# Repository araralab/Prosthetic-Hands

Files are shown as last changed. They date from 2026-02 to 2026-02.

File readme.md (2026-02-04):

*Title:*

**Open-Source Prosthetic Hands for Community Use and STEM Education**

*Authors:*

[Rudy De-Xin de Lange](https://orcid.org/0009-0008-2099-0941), Andrew Japes, [Lucas Ferrari Gerez](https://orcid.org/0000-0002-2997-4672)

*Abstract:*

Prosthetic technologies restore function and independence of millions of individuals worldwide with limb loss and, at the same time, exemplify the complex challenges inherent to human-centred engineering and design. Meanwhile, in the United Kingdom (UK), only a small portion of secondary education students choose to pursue a career in Science, Technology, Engineering and Mathematics (STEM) fields. This creates a large discrepancy between the supply and demand of individuals to fulfil engineering and technology positions. To tackle both challenges, we propose the Ararauna, Macao and Severus open-source, affordable prosthetic hands that range from basic to advanced designs. They are intended 1) for individuals with upper limb differences and 2) as tools to assist in teaching and promoting STEM-related skills in UK secondary education.  We conducted three experiments looking into grasping capabilities, grip strength, and durability. Our results demonstrate that all three hands are suitable for use as an assistive wearable device or as an educational tool. Our work aims to encourage the prosthetic community to provide the general public with more affordable open-source medical devices intended for individual and educational use. Future work focuses on integrating the presented hands within UK secondary school curricula.

*Repository Contents:*

* .STL (individual parts)  & .STEP (assembly) files for the Ararauna, Macao, and Severus prosthetic hands.
* Some (example) code for programming each hand respectively.
* A Bill of Materials (BOM) for each hand.

*The Prosthetic Hands:*

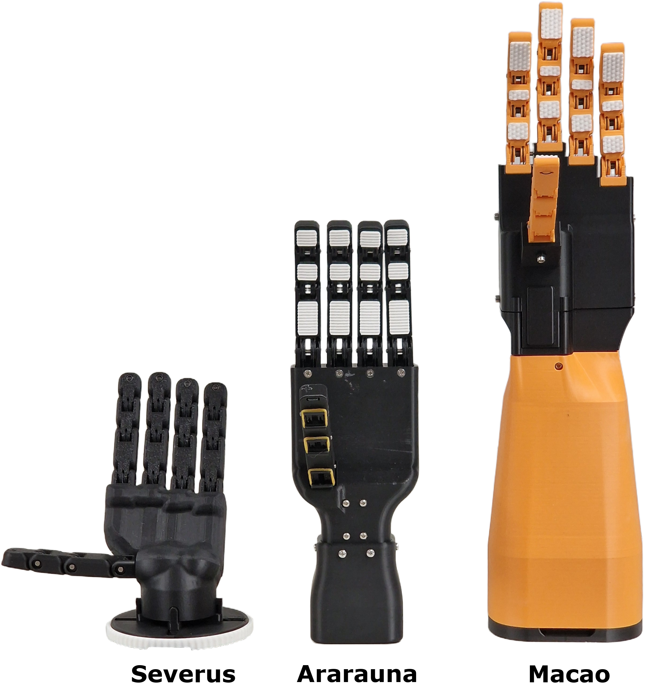
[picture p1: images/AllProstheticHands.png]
All Prosthetic Hands


*Video:*

In the [following video](https://youtu.be/XQv565ON-JM) the capabilities of the three proposed prosthetic hands (Ararauna, Macao, Severus) and two of the three different conducted experiments (Real-world Object Grasping and Grasp Durability) are shown, in that order respectively.

<p align="center">
  <a href="https://youtu.be/XQv565ON-JM">
    Video Title
  </a>
</p>

*Contact:*

For more information, please visit [our website](https://www.araralab.uk/home). Alternatively, please contact the [main author](mailto:3063568D@student.gla.ac.uk) or the [academic supervisor](mailto:Lucas.FerrariGerez@glasgow.ac.uk).

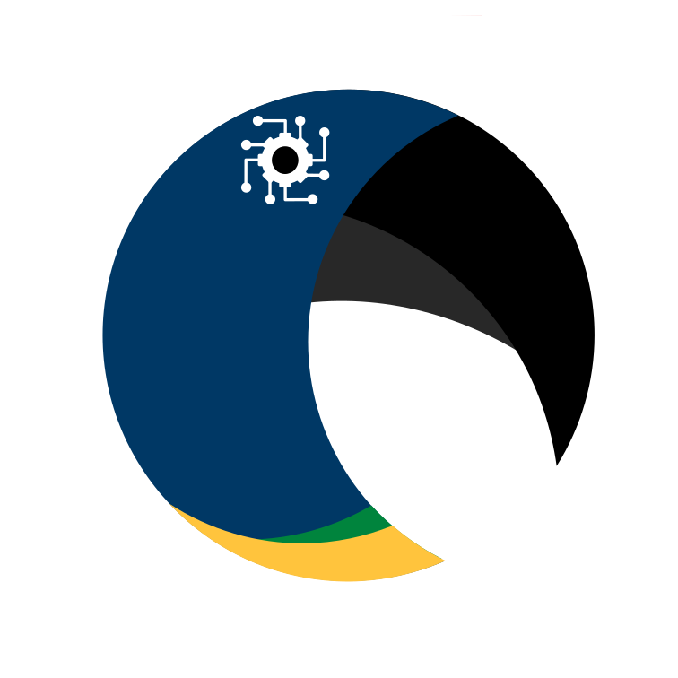
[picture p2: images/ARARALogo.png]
ARARA
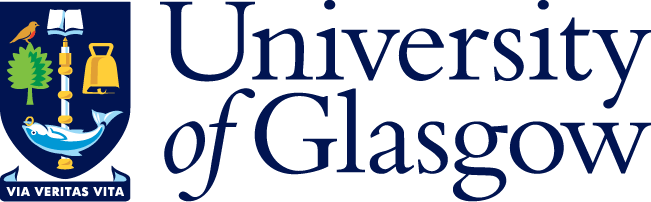
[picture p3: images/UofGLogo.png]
UofG


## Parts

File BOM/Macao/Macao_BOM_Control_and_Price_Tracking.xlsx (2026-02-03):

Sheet: Parts
BoM Control and Price Tracking
Part | Unit Price | Supplier | Notes | Quantity Per Prosthesis | Price Per Prosthesis | Quantity Ordered | Quantity Received | Quantity Used | Link
PLA Filament |  |  |  |  | £0.00
Fishing Line | £8.95 |  | 50lb x 100ft |  | £0.00 | 1.00 | 1.00 |  | https://www.amazon.co.uk/emma-kites-62Meters-Activities-Tactical/dp/B08PBXD5CH?sp_csd=d2lkZ2V0TmFtZT1zcF9hdGY
Orthodontic Bands | £0.01 |  | 4.5oz x 1/8" (£1.19 for 100) |  | £0.00 | 100.00 | 100.00 | 6.00 | https://www.ebay.co.uk/itm/276185566951
M3 Bolt pack | £11.99 |  | (1600 pcs) |  | £0.00 | 1.00 | 1.00 |  | https://www.amazon.co.uk/dp/B0DZXLY1ZX?ref=ppx_yo2ov_dt_b_fed_asin_title&th=1
 |  |  |  |  | £0.00
 |  |  |  |  | £0.00
 |  |  |  |  | £0.00
 |  |  |  |  | £0.00
 |  |  |  |  | £0.00
 |  |  |  |  | £0.00
 |  |  |  |  | £0.00
 |  |  |  |  | £0.00
 |  |  |  |  | £0.00
 |  |  |  |  | £0.00
 |  |  |  |  | £0.00
 |  |  |  |  | £0.00
 |  |  |  |  | £0.00
 |  |  |  |  | £0.00
 |  |  |  |  | £0.00
 |  |  |  |  | £0.00
 |  |  |  |  | £0.00
 |  |  |  |  | £0.00
 |  |  |  |  | £0.00
 |  |  |  |  | £0.00
 |  |  |  |  | £0.00
 |  |  |  |  | £0.00
 |  |  |  |  | £0.00
Prosthesis Parts Value |  |  |  | £0.00
Total Project Value |  |  |  | £22.13

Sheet: Tooling
Tooling Control and Price Tracking
Tool | Unit Price | Supplier | Notes | Link

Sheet: Report BoM
BOM Control and Price Tracking - Macao
Part | Unit Price | Supplier | Notes | Quantity Per Prosthesis | Price Per Prosthesis | Quantity Ordered | Quantity Received | Quantity Used | Stock | Link
PLA Filament | £17.99 | Bambu | PLA Black | 0.70 | £12.59 | 10.00 | 10.00 | 0.70 | 9.30 | https://uk.store.bambulab.com/products/pla-basic-filament
Kevlar Cord | £8.95 | Amazon | 50lb x 100ft | 1.00 | £8.95 | 1.00 | 1.00 | 0.01 | 0.99 | https://www.amazon.co.uk/emma-kites-62Meters-Activities-Tactical/dp/B08PBXD5CH?sp_csd=d2lkZ2V0TmFtZT1zcF9hdGY
Arduino R4 Wifi | £25.00 | the PiHut |  | 1.00 | £25.00 | 10.00 | 10.00 | 1.00 | 9.00 | https://thepihut.com/products/arduino-uno-r4-wifi
DFRobot Quad Motor Shield (DRI0039) | £13.27 | Digikey |  | 1.00 | £13.27 | 8.00 | 8.00 | 1.00 | 7.00 | https://www.digikey.co.uk/en/products/detail/dfrobot/DRI0039/6588612
Dupont Wires Male to Male | £5.63 | Amazon | ~20 per hand | 0.17 | £0.94 | 1.00 | 1.00 | 0.33 | 0.67 | https://www.amazon.co.uk/Elegoo-120pcs-Multicolored-Breadboard-arduino-colorful/dp/B01EV70C78
Actuonix PQ12-P | £60.00 | Robotshop |  | 4.00 | £240.00 | 32.00 | 32.00 | 4.00 | 28.00 | https://uk.robotshop.com/products/actuonix-pq12-p-linear-actuator-20mm-1001-6v-potentiometer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
11.1V Lithium Li-Ion 2600mAH Battery | £10.90 | Amazon |  | 1.00 | £10.90 | 8.00 | 8.00 | 1.00 | 7.00 | https://www.amazon.co.uk/Replacement-Rechargeable-Airplane-Doorbell-Handheld-No-Charger-Cable/dp/B0DCW2WFCP
M3 Threaded heat insert | £0.16 | Accu |  | 16.00 | £2.56 | 500.00 | 500.00 | 1.00 | 499.00 | https://www.accu.co.uk/brass-threaded-inserts/845137-HTBI-M3-BR
M3x8mm Full Thread Socket | £0.08 | Accu |  | 18.00 | £1.44 | 500.00 | 500.00 | 1.00 | 499.00 | https://www.accu.co.uk/metric-cap-head-screws/3974-SSCF-M3-8-A4
M3x12mm Full Thread Socket | £0.07 | Accu |  | 5.00 | £0.35 | 500.00 | 500.00 | 1.00 | 499.00 | https://www.accu.co.uk/metric-cap-head-screws/3976-SSCF-M3-12-A4
M3x12mm Dowel Pin | £0.13 | Accu |  | 15.00 | £1.95 | 400.00 | 400.00 | 1.00 | 399.00 | https://www.accu.co.uk/dowel-pins/72639-HDP-3-12-A1
RS PRO Miniature Push Button | £4.01 | RS Online |  | 4.00 | £16.04 | 32.00 | 32.00 | 1.00 | 31.00 | https://uk.rs-online.com/web/p/push-button-switches/7346710
 |  |  |  |  | £0.00 |  |  |  | 0.00
 |  |  |  |  | £0.00 |  |  |  | 0.00
 |  |  |  |  | £0.00 |  |  |  | 0.00
 |  |  |  |  | £0.00 |  |  |  | 0.00
 |  |  |  |  | £0.00 |  |  |  | 0.00
 |  |  |  |  | £0.00 |  |  |  | 0.00
 |  |  |  |  | £0.00 |  |  |  | 0.00
 |  |  |  |  | £0.00 |  |  |  | 0.00
 |  |  |  |  | £0.00 |  |  |  | 0.00
 |  |  |  |  | £0.00 |  |  |  | 0.00
 |  |  |  |  | £0.00 |  |  |  | 0.00
 |  |  |  |  | £0.00 |  |  |  | 0.00
 |  |  |  |  | £0.00 |  |  |  | 0.00
 |  |  |  |  | £0.00 |  |  |  | 0.00
 |  |  |  |  | £0.00 |  |  |  | 0.00
Prosthesis Parts Value |  |  |  | £333.99
Total Project Value |  |  |  | £2893.16

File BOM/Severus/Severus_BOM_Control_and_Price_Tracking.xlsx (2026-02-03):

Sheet: Parts
BoM Control and Price Tracking
Part | Unit Price | Supplier | Notes | Quantity Per Prosthesis | Price Per Prosthesis | Quantity Ordered | Quantity Received | Quantity Used | Link
PLA Filament |  |  |  |  | £0.00
Fishing Line | £8.95 |  | 50lb x 100ft |  | £0.00 | 1.00 | 1.00 |  | https://www.amazon.co.uk/emma-kites-62Meters-Activities-Tactical/dp/B08PBXD5CH?sp_csd=d2lkZ2V0TmFtZT1zcF9hdGY
Orthodontic Bands | £0.01 |  | 4.5oz x 1/8" (£1.19 for 100) |  | £0.00 | 100.00 | 100.00 | 6.00 | https://www.ebay.co.uk/itm/276185566951
M3 Bolt pack | £11.99 |  | (1600 pcs) |  | £0.00 | 1.00 | 1.00 |  | https://www.amazon.co.uk/dp/B0DZXLY1ZX?ref=ppx_yo2ov_dt_b_fed_asin_title&th=1
 |  |  |  |  | £0.00
 |  |  |  |  | £0.00
 |  |  |  |  | £0.00
 |  |  |  |  | £0.00
 |  |  |  |  | £0.00
 |  |  |  |  | £0.00
 |  |  |  |  | £0.00
 |  |  |  |  | £0.00
 |  |  |  |  | £0.00
 |  |  |  |  | £0.00
 |  |  |  |  | £0.00
 |  |  |  |  | £0.00
 |  |  |  |  | £0.00
 |  |  |  |  | £0.00
 |  |  |  |  | £0.00
 |  |  |  |  | £0.00
 |  |  |  |  | £0.00
 |  |  |  |  | £0.00
 |  |  |  |  | £0.00
 |  |  |  |  | £0.00
 |  |  |  |  | £0.00
 |  |  |  |  | £0.00
 |  |  |  |  | £0.00
Prosthesis Parts Value |  |  |  | £0.00
Total Project Value |  |  |  | £22.13

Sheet: Tooling
Tooling Control and Price Tracking
Tool | Unit Price | Supplier | Notes | Link

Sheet: Report BoM
BOM Control and Price Tracking - Severus
Part | Unit Price | Supplier | Notes | Quantity Per Prosthesis | Price Per Prosthesis | Quantity Ordered | Quantity Received | Quantity Used | Stock | Link
PLA Filament | £18.99 | Creality | Hyper PLA (Black) - 1kg | 0.35 | £6.65 | 1.00 | 1.00 | 0.70 | 0.30 | Hyper 1.75mm PLA 3D Printing Filament 1kg (https://store.creality.com/uk/products/hyper-1-75mm-pla-3d-printing-filament-1kg)
Kevlar Cord | £8.95 | Amazon | 50lb x 100ft | 0.03 | £0.27 | 1.00 | 1.00 | 0.05 | 0.95 | https://www.amazon.co.uk/emma-kites-62Meters-Activities-Tactical/dp/B08PBXD5CH?sp_csd=d2lkZ2V0TmFtZT1zcF9hdGY
Orthodontic Bands | £0.01 | Ebay | 4.5oz x 1/8" (£1.19 for 100) | 15.00 | £0.18 | 100.00 | 100.00 | 6.00 | 94.00 | https://www.ebay.co.uk/itm/276185566951
M3 Bolt pack | £0.01 | Amazon | (1600 pcs) | 46.00 | £0.34 | 1600.00 | 1600.00 | 60.00 | 1540.00 | https://www.amazon.co.uk/dp/B0DZXLY1ZX?ref=ppx_yo2ov_dt_b_fed_asin_title&th=1
Barrel Nuts/Binding screws | £0.30 | Harfington | M2 x 12mm | 15.00 | £4.50 | 20.00 | 20.00 | 19.00 | 1.00 | M2/M3/M4/M5 Binding Barrels and Screws Hex Socket Drive 18-8 Stainless Steel | Harfington (https://www.harfington.com/en-gb/products/p-1528129?variant=45273319047417)
Nylon Shoulder Washers | £0.10 | Components Direct |  | 30.00 | £3.01 | 100.00 | 100.00 | 36.00 | 64.00 | Buy Nylon Shoulder Bushes | Machine Screw Insulators (https://www.components-direct.com/component-and-fastener-products/nylon-shoulder-washers-machine-screw-insulators/INS003-NAT)
Micro-metal Geared Motor (100:1) | £11.50 | The Pi Hut |  | 5.00 | £57.50 | 5.00 | 5.00 | 5.00 | 0.00 | Micro Metal Geared Motor with Encoder - 6V 155RPM 100:1 - The Pi Hut (https://thepihut.com/products/micro-metal-geared-motor-w-encoder-6v-155rpm-100-1)
Micro-metal Geared Motor (380:1) | £11.50 | The Pi Hut |  | 1.00 | £11.50 | 2.00 | 2.00 | 1.00 | 1.00 | Micro Metal Geared motor with Encoder - 6V 41RPM 380:1 - The Pi Hut (https://thepihut.com/products/micro-metal-geared-motor-w-encoder-6v-41rpm-380-1)
2N7000 MOSFET Transistor | £0.08 | Amazon |  | 6.00 | £0.48 | 100.00 | 100.00 | 8.00 | 92.00 | ACOLY 100 Pcs Direct Insertion Transistor 2N7000 TO-92 N-Channel Feld Effect Transistor 0.3A 60V : Amazon.co.uk: Business, Industry & Science (https://www.amazon.co.uk/dp/B0FVX46NM9?ref_=pe_112168041_1111392281_t_fed_asin_title)
220 Ohm Resistor | £0.01 | RS |  | 6.00 | £0.06 |  |  |  | 0.00
10K Ohm Resistor | £0.01 | RS |  | 6.00 | £0.06 |  |  |  | 0.00
100K Ohm Resistor | £0.01 | RS |  | 6.00 | £0.06 |  |  |  | 0.00
STM32F411CEU6 Blackpill Development Board | £15.90 | The Pi Hut |  | 1.00 | £15.90 | 1.00 | 1.00 | 1.00 | 0.00 | STM32F411 "BlackPill" Development Board - The Pi Hut (https://thepihut.com/products/stm32f411-blackpill-development-board)
TB6612FNG Dual Motor Driver Board | £5.80 | The Pi Hut |  | 3.00 | £17.40 | 3.00 | 3.00 | 3.00 | 0.00 | Pololu TB6612FNG Dual Motor Driver Carrier - The Pi Hut (https://thepihut.com/products/pololu-tb6612fng-dual-motor-driver-carrier)
M3 Threaded heat-press inserts | £0.08 | 3D Prima | Ruthex inserts | 5.00 | £0.38 | 100.00 | 100.00 | 12.00 | 88.00 | Ruthex M3 threaded insert – Rx-M3x5.7 - 100 pcs | 3D Prima (https://www.3dprima.co.uk/ruthex-m3-threaded-insert-rx-m3x5-7-100-pcs-12611)
 |  |  |  |  | £0.00 |  |  |  | 0.00
 |  |  |  |  | £0.00 |  |  |  | 0.00
 |  |  |  |  | £0.00 |  |  |  | 0.00
 |  |  |  |  | £0.00 |  |  |  | 0.00
 |  |  |  |  | £0.00 |  |  |  | 0.00
 |  |  |  |  | £0.00 |  |  |  | 0.00
 |  |  |  |  | £0.00 |  |  |  | 0.00
 |  |  |  |  | £0.00 |  |  |  | 0.00
 |  |  |  |  | £0.00 |  |  |  | 0.00
 |  |  |  |  | £0.00 |  |  |  | 0.00
 |  |  |  |  | £0.00 |  |  |  | 0.00
 |  |  |  |  | £0.00 |  |  |  | 0.00
Prosthesis Parts Value |  |  |  | £118.28
Total Project Value |  |  |  | £186.50

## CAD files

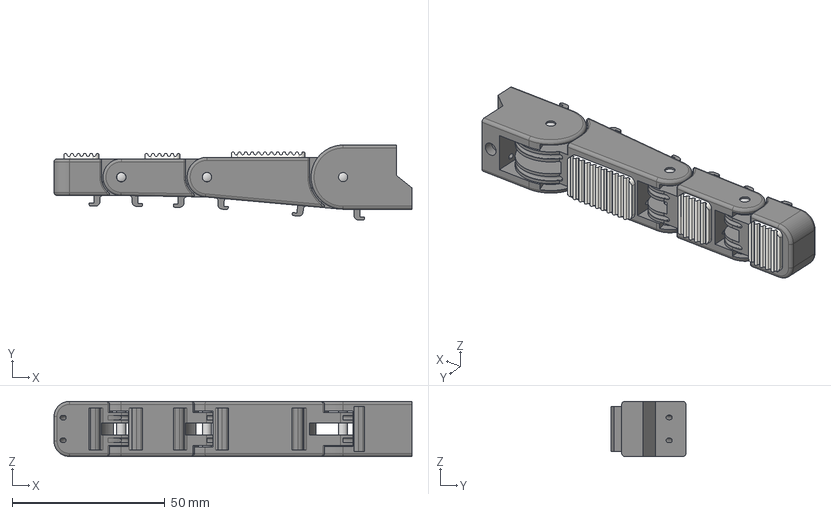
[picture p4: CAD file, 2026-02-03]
.STL&.STEP/Ararauna/Assembly/Ararauna Finger Assembly.step
117.0 x 24.5 x 18.0 mm
Basic_Finger_Distal v19
Basic_Finger_Middle v16
Basic_Finger_Proximal v13
Base
Basic_Finger_Proximal_Pad v9
Basic_Finger_Middle_Pad v11
Basic_Finger_Middle_Pad v11 (1)
91595A118_Dowel Pin
91595A118_Dowel Pin_1
91595A118_Dowel Pin_2

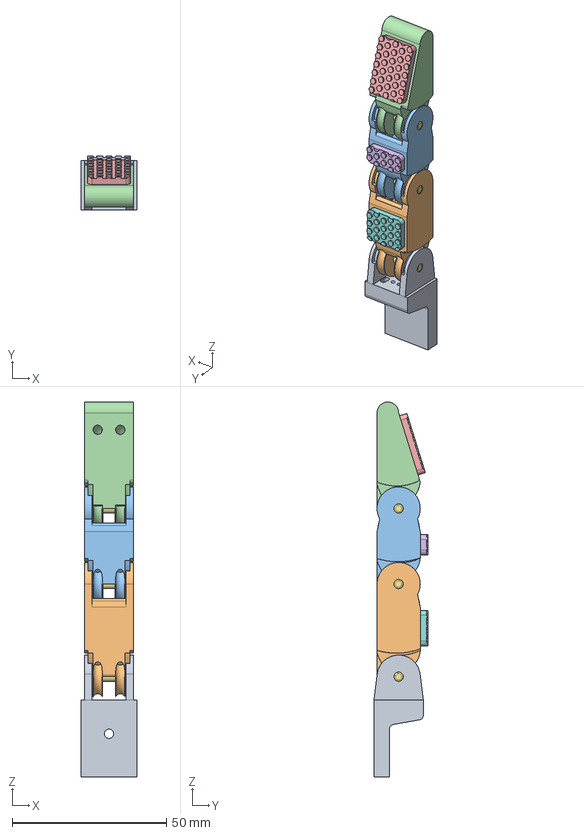
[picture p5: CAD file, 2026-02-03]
.STL&.STEP/Macao/Assembly/Macao Finger Assembly.step
18.0 x 17.5 x 121.5 mm
Finger Base
Finger First Phalange
Finger Medial Phalange
Finger Distal Phalange
Finger Distal Pad
Finger Medial Pad
Dowel Pin Distal
Dowel Pin Medial
Finger First Pad
Dowel Pin Base

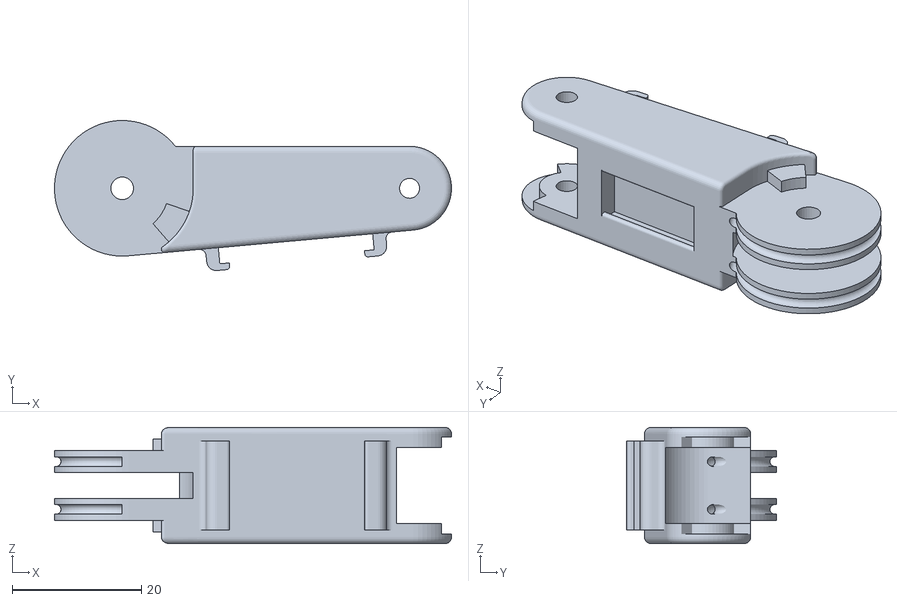
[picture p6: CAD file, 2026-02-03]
.STL&.STEP/Ararauna/Fingers/Finger Proximal Phalange.stl
61.5 x 23.2 x 18.0

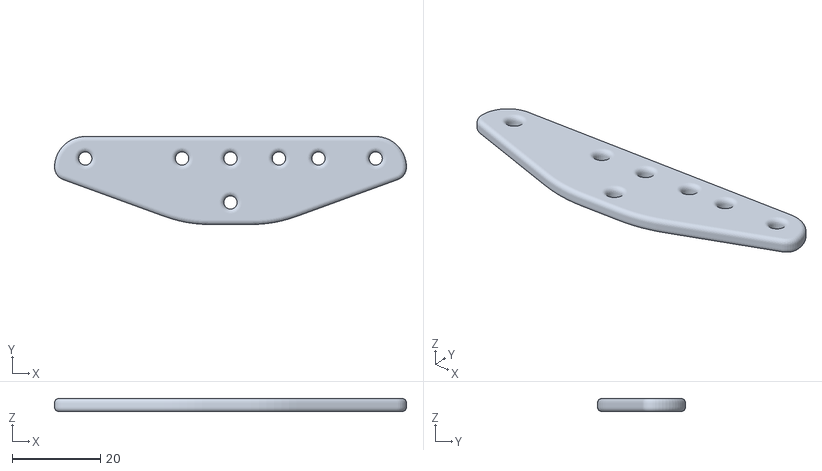
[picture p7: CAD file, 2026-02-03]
.STL&.STEP/Ararauna/Hand/Finger Differential.stl
80.0 x 20.0 x 3.00

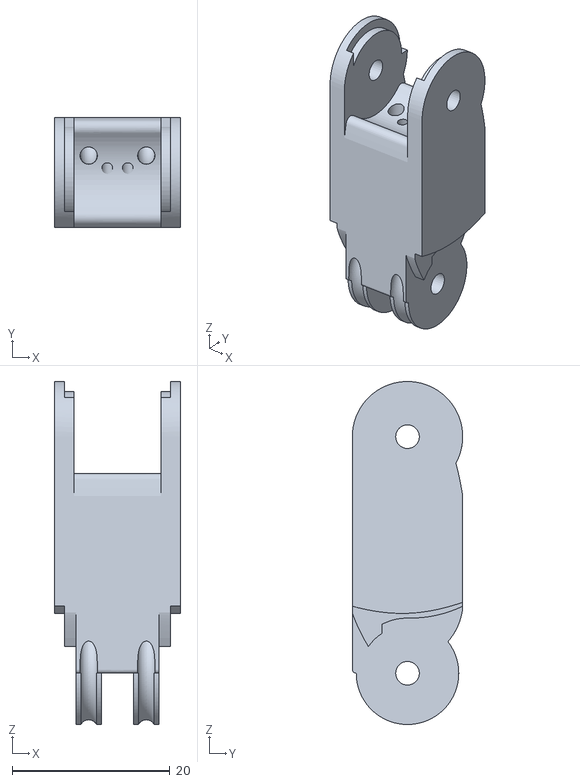
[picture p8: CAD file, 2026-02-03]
.STL&.STEP/Macao/Fingers/Finger First Phalange.stl
16.0 x 14.0 x 43.5

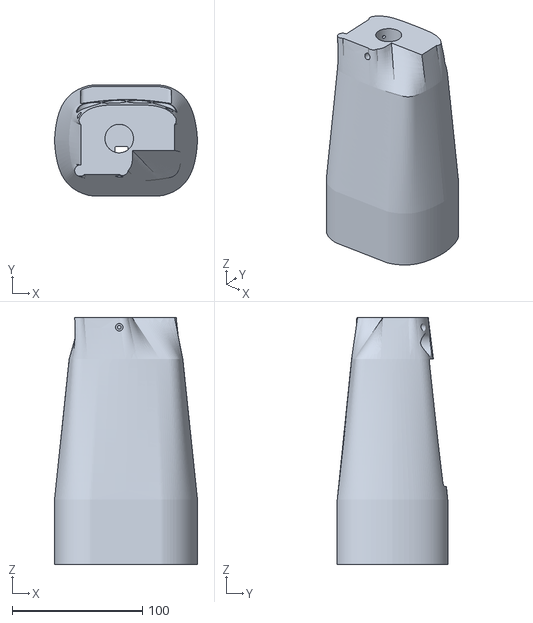
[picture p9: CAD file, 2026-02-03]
.STL&.STEP/Macao/Forearm/Short Forearm.stl
110.0 x 85.0 x 190.0

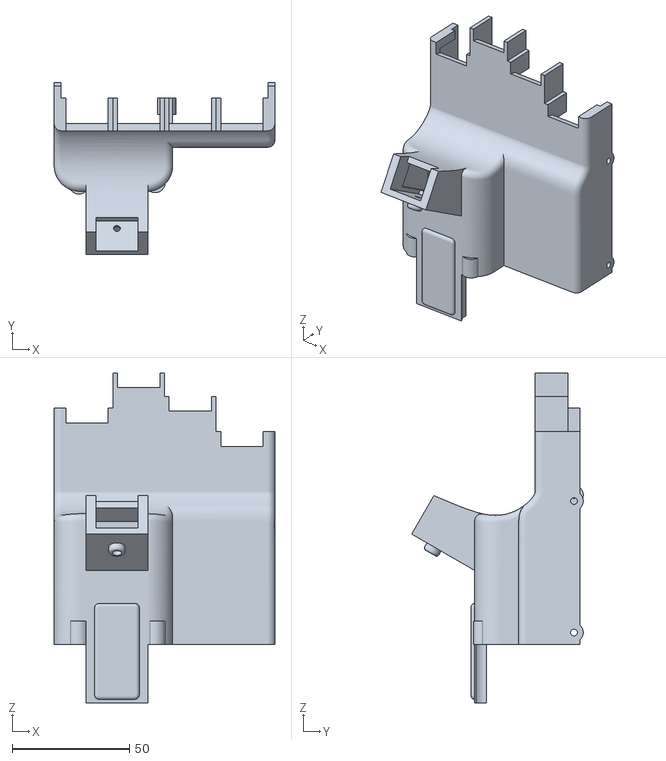
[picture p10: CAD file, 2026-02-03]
.STL&.STEP/Macao/Hand/HandPalm Outer Segment.stl
94.0 x 73.1 x 140.6

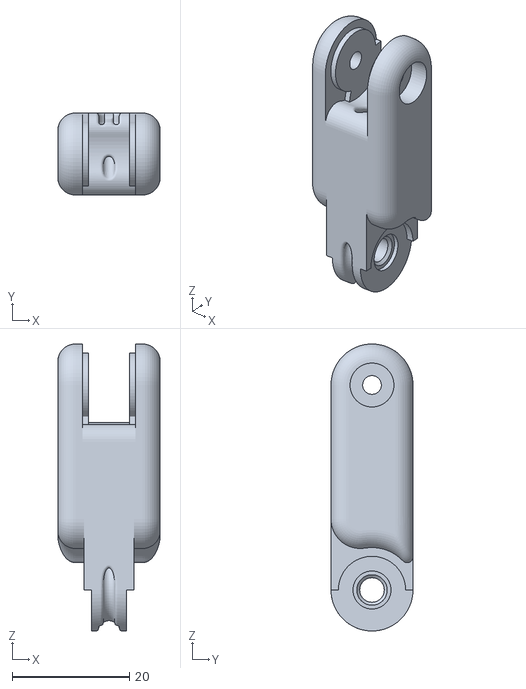
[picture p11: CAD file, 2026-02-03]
.STL&.STEP/Severus/Fingers/Proximal Phalange.stl
17.5 x 14.0 x 49.0

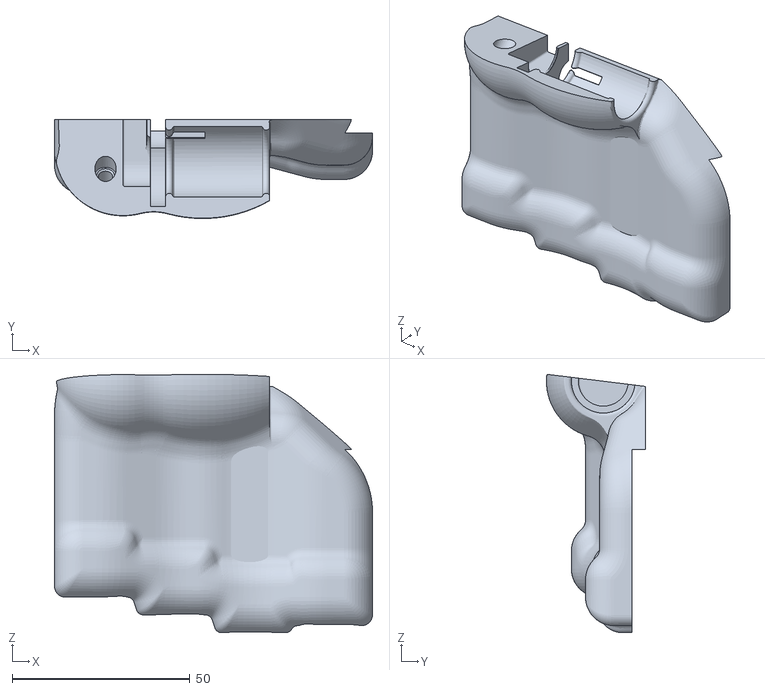
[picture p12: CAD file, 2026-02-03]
.STL&.STEP/Severus/Hand/Palm.stl
89.4 x 27.9 x 72.6

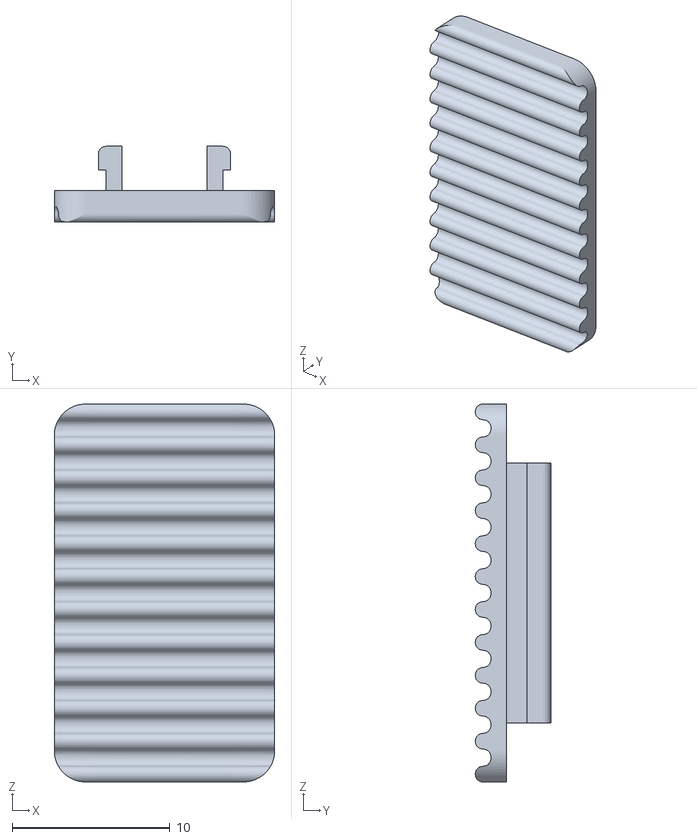
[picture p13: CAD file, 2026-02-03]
.STL&.STEP/Ararauna/Fingers/Finger Proximal Pad.stl
14.0 x 4.80 x 24.0

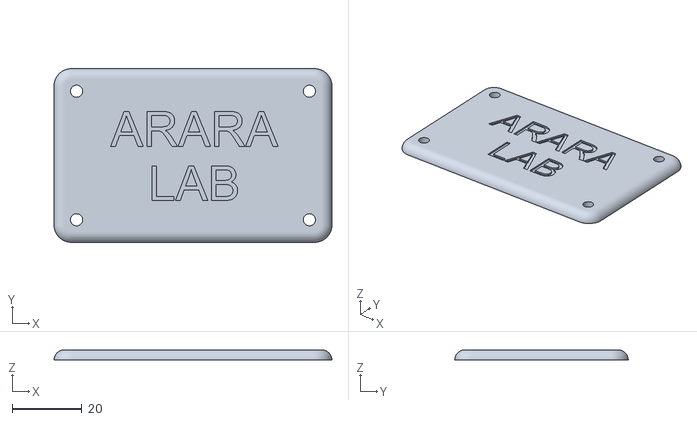
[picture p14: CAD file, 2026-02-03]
.STL&.STEP/Ararauna/Hand/Back Cover.stl
80.0 x 50.0 x 3.00

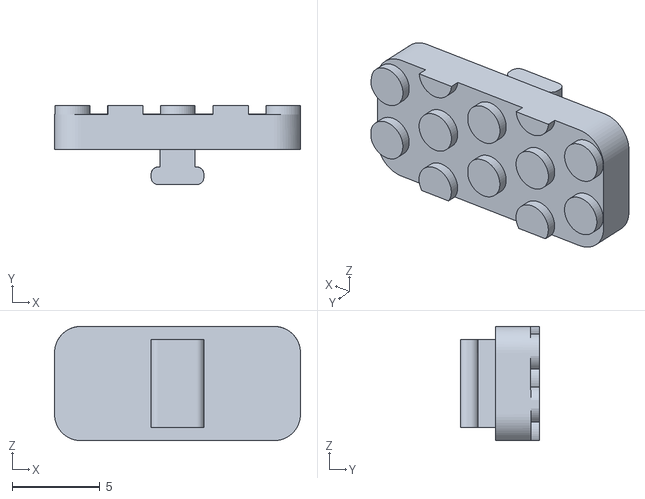
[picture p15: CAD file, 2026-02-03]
.STL&.STEP/Macao/Fingers/Finger Medial Pad.stl
14.0 x 4.51 x 6.50

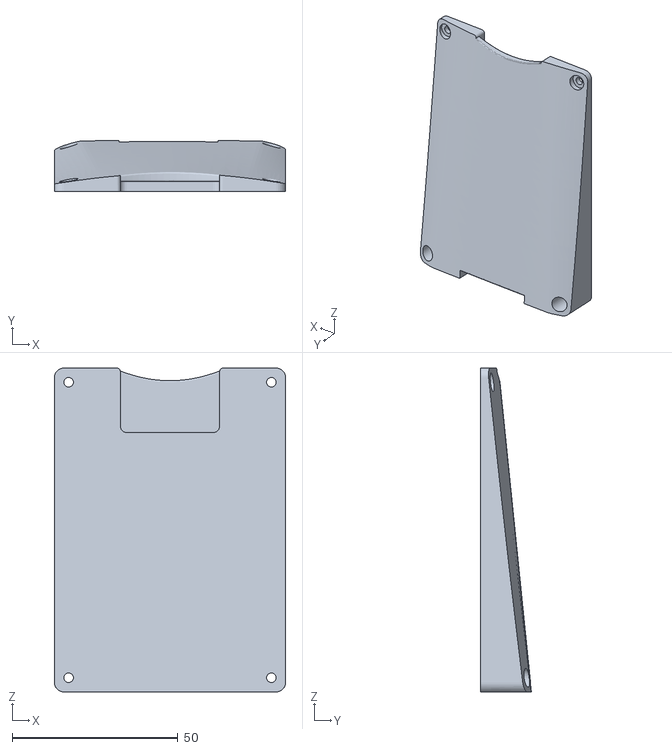
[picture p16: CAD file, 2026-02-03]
.STL&.STEP/Macao/Forearm/Short Forearm Arduino Cavity Lid.stl
69.8 x 15.3 x 97.8

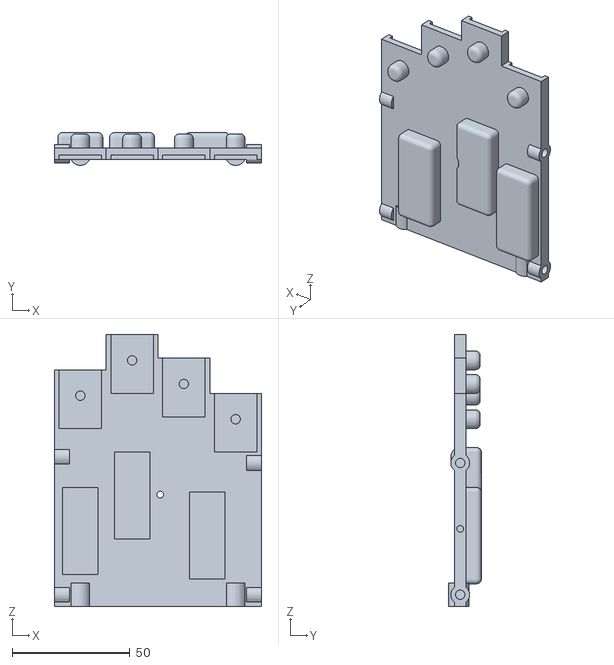
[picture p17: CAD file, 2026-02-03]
.STL&.STEP/Macao/Hand/HandPalm Middle Segment.stl
88.0 x 13.9 x 115.6

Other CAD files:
.STL&.STEP/Severus/Fingers/Thumb Motor Holder.stl
.STL&.STEP/Severus/Hand/Wrist.stl
.STL&.STEP/Ararauna/Fingers/Finger Middle Phalange.stl
.STL&.STEP/Ararauna/Hand/Hand Palm.stl
.STL&.STEP/Ararauna/Fingers/Finger Base.stl
.STL&.STEP/Ararauna/Fingers/Finger Distal Phalange.stl
.STL&.STEP/Ararauna/Fingers/Finger Middle Pad.stl
.STL&.STEP/Ararauna/Hand/Wrist.stl
.STL&.STEP/Macao/Fingers/Finger Base.stl
.STL&.STEP/Macao/Fingers/Finger Distal Pad.stl
.STL&.STEP/Macao/Fingers/Finger Distal Phalange.stl
.STL&.STEP/Macao/Fingers/Finger First Pad.stl
.STL&.STEP/Macao/Fingers/Finger Medial Phalange.stl
.STL&.STEP/Macao/Forearm/Short Forearm Base Lid.stl
.STL&.STEP/Macao/Hand/Palm Cover.stl
.STL&.STEP/Severus/Fingers/Distal Phalange.stl
.STL&.STEP/Severus/Fingers/Finger Motor Holder.stl
.STL&.STEP/Severus/Fingers/Fingernail Phalange.stl
.STL&.STEP/Severus/Fingers/Middle Phalange.stl
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

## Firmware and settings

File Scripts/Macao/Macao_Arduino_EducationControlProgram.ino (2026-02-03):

//////////////////////////////////////////////////////////////////////////////
// Button & Keyboard-Controlled Multi-Grasp System for ARARA UNO Prosthetic //
//////////////////////////////////////////////////////////////////////////////
// Button 1 (Pin 2):  Open Hand
// Button 2 (Pin 9):  Power Grasp (all fingers closed)
// Button 3 (Pin 10): Fine Pinch (thumb + middle closed)
// Button 4 (Pin 13): Tripod (thumb + middle + index closed)
//
// Keyboard Controls (via Serial):
// Key 0: Open Hand (all fingers extended)
// Key 1: Power Grasp (all fingers closed)
// Key 2: Fine Pinch (thumb + middle closed, index + ring+pinky extended)
// Key 3: Tripod (thumb + middle + index closed, ring+pinky extended)
// Key 4: Point (thumb + middle + ring+pinky closed, index extended)
// Key 5: Peace Sign (thumb + ring+pinky closed, index + middle extended)
// Key 6: Close Thumb only
// Key 7: Close Index only
// Key 8: Close Middle only
// Key 9: Close Ring+Pinky only
//////////////////////////////////////////////////////////////////////////////
// Written & Maintained by: Rudy de Lange (3063568D@student.gla.ac.uk)
// Last maintained: 13/01/2026 - Added button control + Fixed Logic
//////////////////////////////////////////////////////////////////////////////

// Motor pins
#define M1_DIR 7     // Middle finger (physically wired)
#define E1_PWM 6
#define M2_DIR 4     // Index Finger
#define E2_PWM 3
#define M3_DIR 8     // Thumb
#define E3_PWM 5
#define M4_DIR 12    // Ring + Pinky (physically wired)
#define E4_PWM 11

// Button pins
#define BUTTON_1 1   // Open Hand
#define BUTTON_2 9   // Power Grasp
#define BUTTON_3 13  // Fine Pinch
#define BUTTON_4 10  // Tripod

// Timing constants
#define FINGER_EXTEND_TIME 3000
#define FINGER_RETRACT_TIME 3000
#define THUMB_RETRACT_TIME 3000    
#define THUMB_DELAY 480            // Delay before thumb starts closing
#define THUMB_PINCH_DELAY 200      // Delay before thumb starts closing for fine pinch
#define DEBOUNCE_DELAY 50          // Button debounce delay in ms

// Motor speeds
#define MOTOR_SPEED 255

// State tracking
enum GraspType {
  OPEN,
  POWER_GRASP,
  FINE_PINCH,
  TRIPOD,
  POINT,
  PEACE_SIGN,
  THUMB_ONLY,
  INDEX_ONLY,
  MIDDLE_ONLY,
  RING_PINKY_ONLY
};

GraspType currentGrasp = OPEN;

// Button state tracking
int lastBtn1 = HIGH;
int lastBtn2 = HIGH;
int lastBtn3 = HIGH;
int lastBtn4 = HIGH;

void setup() {
  Serial.begin(9600);
  Serial.println(F("=== Multi-Grasp Control System ==="));
  Serial.println(F("--- Button Controls ---"));
  Serial.println(F("Button 1 (Pin 2):  Open Hand"));
  Serial.println(F("Button 2 (Pin 9):  Power Grasp"));
  Serial.println(F("Button 3 (Pin 10): Fine Pinch"));
  Serial.println(F("Button 4 (Pin 13): Tripod"));
  Serial.println(F("--- Keyboard Controls ---"));
  Serial.println(F("0: Open Hand"));
  Serial.println(F("1: Power Grasp"));
  Serial.println(F("2: Fine Pinch"));
  Serial.println(F("3: Tripod"));
  Serial.println(F("4: Point"));
  Serial.println(F("5: Peace Sign"));
  Serial.println(F("6: Close Thumb only"));
  Serial.println(F("7: Close Index only"));
  Serial.println(F("8: Close Middle only"));
  Serial.println(F("9: Close Ring+Pinky only"));

  // Initialize motor pins
  pinMode(M1_DIR, OUTPUT);
  pinMode(E1_PWM, OUTPUT);
  pinMode(M2_DIR, OUTPUT);
  pinMode(E2_PWM, OUTPUT);
  pinMode(M3_DIR, OUTPUT);
  pinMode(E3_PWM, OUTPUT);
  pinMode(M4_DIR, OUTPUT);
  pinMode(E4_PWM, OUTPUT);

  // Initialize button pins with internal pull-up resistors
  pinMode(BUTTON_1, INPUT_PULLUP);
  pinMode(BUTTON_2, INPUT_PULLUP);
  pinMode(BUTTON_3, INPUT_PULLUP);
  pinMode(BUTTON_4, INPUT_PULLUP);

  // Stop all motors
  digitalWrite(M1_DIR, LOW);
  digitalWrite(M2_DIR, LOW);
  digitalWrite(M3_DIR, LOW);
  digitalWrite(M4_DIR, LOW);
  analogWrite(E1_PWM, 0);
  analogWrite(E2_PWM, 0);
  analogWrite(E3_PWM, 0);
  analogWrite(E4_PWM, 0);

  delay(1000);

  // Initialize to open position
  Serial.println(F("Initializing to open position..."));
  openAllFingers();

  Serial.println(F("Ready!"));
}

void loop() {
  // Check button inputs
  checkButtons();

  // Check serial keyboard inputs
  if (Serial.available() > 0) {
    char key = Serial.read();
    handleKeyboardInput(key);
  }

  delay(10);
}

// ========== BUTTON HANDLING ==========

void checkButtons() {
  // Read button states
  int btn1 = digitalRead(BUTTON_1);
  int btn2 = digitalRead(BUTTON_2);
  int btn3 = digitalRead(BUTTON_3);
  int btn4 = digitalRead(BUTTON_4);

  // Button 1 - Open Hand (trigger on press: LOW->HIGH transition)
  if (btn1 != lastBtn1) {
    if (btn1 == HIGH) {  // Button pressed (HIGH = pressed)
      Serial.println(F("Button 1 pressed: Open Hand"));
      openAllFingers();
      currentGrasp = OPEN;
      Serial.println(F(">>> OPEN"));
    }
    lastBtn1 = btn1;
    delay(50);  // Debounce
  }

  // Button 2 - Power Grasp
  if (btn2 != lastBtn2) {
    if (btn2 == HIGH) {  // Button pressed
      Serial.println(F("Button 2 pressed: Power Grasp"));
      if (currentGrasp == POWER_GRASP) {
        openAllFingers();
        currentGrasp = OPEN;
        Serial.println(F(">>> OPEN"));
      } else if (currentGrasp == OPEN) {
        performPowerGrasp();
        currentGrasp = POWER_GRASP;
        Serial.println(F(">>> POWER GRASP"));
      } else {
        Serial.println(F("ERROR: Release hand first (press Button 1)"));
      }
    }
    lastBtn2 = btn2;
    delay(50);
  }

  // Button 3 - Fine Pinch
  if (btn3 != lastBtn3) {
    if (btn3 == HIGH) {  // Button pressed
      Serial.println(F("Button 3 pressed: Fine Pinch"));
      if (currentGrasp == FINE_PINCH) {
        openAllFingers();
        currentGrasp = OPEN;
        Serial.println(F(">>> OPEN"));
      } else if (currentGrasp == OPEN) {
        performFinePinch();
        currentGrasp = FINE_PINCH;
        Serial.println(F(">>> FINE PINCH"));
      } else {
        Serial.println(F("ERROR: Release hand first (press Button 1)"));
      }
    }
    lastBtn3 = btn3;
    delay(50);
  }

  // Button 4 - Tripod
  if (btn4 != lastBtn4) {
    if (btn4 == HIGH) {  // Button pressed
      Serial.println(F("Button 4 pressed: Tripod"));
      if (currentGrasp == TRIPOD) {
        openAllFingers();
        currentGrasp = OPEN;
        Serial.println(F(">>> OPEN"));
      } else if (currentGrasp == OPEN) {
        performTripod();
        currentGrasp = TRIPOD;
        Serial.println(F(">>> TRIPOD"));
      } else {
        Serial.println(F("ERROR: Release hand first (press Button 1)"));
      }
    }
    lastBtn4 = btn4;
    delay(50);
  }
}

// ========== KEYBOARD HANDLING ==========

void handleKeyboardInput(char key) {
  switch (key) {
    case '0':
      openAllFingers();
      currentGrasp = OPEN;
      Serial.println(F(">>> OPEN"));
      break;

    case '1':
      if (currentGrasp == POWER_GRASP) {
        openAllFingers();
        currentGrasp = OPEN;
        Serial.println(F(">>> OPEN"));
      } else if (currentGrasp == OPEN) {
        performPowerGrasp();
        currentGrasp = POWER_GRASP;
        Serial.println(F(">>> POWER GRASP"));
      } else {
        Serial.println(F("ERROR: Release hand first (press 0 or Button 1)"));
      }
      break;

    case '2':
      if (currentGrasp == FINE_PINCH) {
        openAllFingers();
        currentGrasp = OPEN;
        Serial.println(F(">>> OPEN"));
      } else if (currentGrasp == OPEN) {
        performFinePinch();
        currentGrasp = FINE_PINCH;
        Serial.println(F(">>> FINE PINCH"));
      } else {
        Serial.println(F("ERROR: Release hand first (press 0 or Button 1)"));
      }
      break;

    case '3':
      if (currentGrasp == TRIPOD) {
        openAllFingers();
        currentGrasp = OPEN;
        Serial.println(F(">>> OPEN"));
      } else if (currentGrasp == OPEN) {
        performTripod();
        currentGrasp = TRIPOD;
        Serial.println(F(">>> TRIPOD"));
      } else {
        Serial.println(F("ERROR: Release hand first (press 0 or Button 1)"));
      }
      break;

    case '4':
      if (currentGrasp == POINT) {
        openAllFingers();
        currentGrasp = OPEN;
        Serial.println(F(">>> OPEN"));
      } else if (currentGrasp == OPEN) {
        performPoint();
        currentGrasp = POINT;
        Serial.println(F(">>> POINT"));
      } else {
        Serial.println(F("ERROR: Release hand first (press 0 or Button 1)"));
      }
      break;

    case '5':
      if (currentGrasp == PEACE_SIGN) {
        openAllFingers();
        currentGrasp = OPEN;
        Serial.println(F(">>> PEACE SIGN"));
      } else if (currentGrasp == OPEN) {
        performPeaceSign();
        currentGrasp = PEACE_SIGN;
        Serial.println(F(">>> PEACE SIGN"));
      } else {
        Serial.println(F("ERROR: Release hand first (press 0 or Button 1)"));
      }
      break;

    case '6':
      if (currentGrasp == THUMB_ONLY) {
        openAllFingers();
        currentGrasp = OPEN;
        Serial.println(F(">>> THUMB ONLY"));
      } else if (currentGrasp == OPEN) {
        performThumbOnly();
        currentGrasp = THUMB_ONLY;
        Serial.println(F(">>> THUMB ONLY"));
      } else {
        Serial.println(F("ERROR: Release hand first (press 0 or Button 1)"));
      }
      break;

    case '7':
      if (currentGrasp == INDEX_ONLY) {
        openAllFingers();
        currentGrasp = OPEN;
        Serial.println(F(">>> INDEX ONLY"));
      } else if (currentGrasp == OPEN) {
        performIndexOnly();
        currentGrasp = INDEX_ONLY;
        Serial.println(F(">>> INDEX ONLY"));
      } else {
        Serial.println(F("ERROR: Release hand first (press 0 or Button 1)"));
      }
      break;

    case '8':
      if (currentGrasp == MIDDLE_ONLY) {
        openAllFingers();
        currentGrasp = OPEN;
        Serial.println(F(">>> MIDDLE ONLY"));
      } else if (currentGrasp == OPEN) {
        performMiddleOnly();
        currentGrasp = MIDDLE_ONLY;
        Serial.println(F(">>> MIDDLE ONLY"));
      } else {
        Serial.println(F("ERROR: Release hand first (press 0 or Button 1)"));
      }
      break;

    case '9':
      if (currentGrasp == RING_PINKY_ONLY) {
        openAllFingers();
        currentGrasp = OPEN;
        Serial.println(F(">>> RING+PINKY ONLY"));
      } else if (currentGrasp == OPEN) {
        performRingPinkyOnly();
        currentGrasp = RING_PINKY_ONLY;
        Serial.println(F(">>> RING+PINKY ONLY"));
      } else {
        Serial.println(F("ERROR: Release hand first (press 0 or Button 1)"));
      }
      break;
  }
}

// ========== HELPER FUNCTIONS ==========

void openAllFingers() {
  Serial.println(F("Opening all fingers..."));

  // Set all to extend
  digitalWrite(M1_DIR, LOW);    // Middle extend 
  digitalWrite(M2_DIR, HIGH);   // Index extend
  digitalWrite(M3_DIR, HIGH);   // Thumb extend
  digitalWrite(M4_DIR, LOW);    // Ring+Pinky extend 

  // Start all motors
  analogWrite(E1_PWM, MOTOR_SPEED);
  analogWrite(E2_PWM, MOTOR_SPEED);
  analogWrite(E3_PWM, MOTOR_SPEED);
  analogWrite(E4_PWM, MOTOR_SPEED);

  delay(FINGER_EXTEND_TIME);

  // Stop all motors
  analogWrite(E1_PWM, 0);
  analogWrite(E2_PWM, 0);
  analogWrite(E3_PWM, 0);
  analogWrite(E4_PWM, 0);
}

void stopAllMotors() {
  analogWrite(E1_PWM, 0);
  analogWrite(E2_PWM, 0);
  analogWrite(E3_PWM, 0);
  analogWrite(E4_PWM, 0);
}

// ========== GRASP FUNCTIONS ==========

void performPowerGrasp() {
  // Close: Index, Ring+Pinky, Middle, Thumb (delayed)
  Serial.println(F("Power Grasp..."));

  // Set directions
  digitalWrite(M1_DIR, HIGH);   // Middle retract 
  digitalWrite(M2_DIR, LOW);    // Index retract
  digitalWrite(M3_DIR, LOW);    // Thumb retract
  digitalWrite(M4_DIR, HIGH);   // Ring+Pinky retract 

  // Start fingers first (not thumb)
  analogWrite(E2_PWM, MOTOR_SPEED);  // Index
  analogWrite(E1_PWM, MOTOR_SPEED);  // Middle 
  analogWrite(E4_PWM, MOTOR_SPEED);  // Ring+Pinky 

  delay(THUMB_DELAY);
  // Start thumb
  analogWrite(E3_PWM, MOTOR_SPEED);
  delay(THUMB_RETRACT_TIME);
  // Stop thumb at 50%
  analogWrite(E3_PWM, 0);

  // Wait for other fingers to finish
  delay(FINGER_RETRACT_TIME - THUMB_RETRACT_TIME - THUMB_DELAY);

  stopAllMotors();
}

void performFinePinch() {
  Serial.println(F("Fine Pinch..."));

  // Retract index and thumb only
  digitalWrite(M2_DIR, LOW);    // Index retract
  digitalWrite(M3_DIR, LOW);    // Thumb retract

  analogWrite(E2_PWM, MOTOR_SPEED);  // Index

  delay(THUMB_PINCH_DELAY);
  // Start thumb
  analogWrite(E3_PWM, MOTOR_SPEED);
  delay(THUMB_RETRACT_TIME);
  // Stop thumb at 50%
  analogWrite(E3_PWM, 0);

  // Wait for Index to finish
  delay(FINGER_RETRACT_TIME - THUMB_RETRACT_TIME);

  stopAllMotors();
}

void performTripod() {
  Serial.println(F("Tripod..."));

  // Retract index, middle, and thumb (keep ring+pinky extended)
  digitalWrite(M2_DIR, LOW);    // Index retract
  digitalWrite(M3_DIR, LOW);    // Thumb retract
  digitalWrite(M1_DIR, HIGH);   // Middle retract

  analogWrite(E2_PWM, MOTOR_SPEED);  // Index
  analogWrite(E1_PWM, MOTOR_SPEED);  // Middle

  delay(THUMB_DELAY);
  // Start thumb
  analogWrite(E3_PWM, MOTOR_SPEED);
  delay(THUMB_RETRACT_TIME);
  // Stop thumb at 50%
  analogWrite(E3_PWM, 0);

  // Wait for other fingers to finish
  delay(FINGER_RETRACT_TIME - THUMB_RETRACT_TIME - THUMB_DELAY);

  stopAllMotors();
}

void performPoint() {
  Serial.println(F("Point..."));

  // Retract middle, ring+pinky, and thumb (keep index extended)
  digitalWrite(M1_DIR, HIGH);   // Middle retract
  digitalWrite(M3_DIR, LOW);    // Thumb retract
  digitalWrite(M4_DIR, HIGH);   // Ring+Pinky retract

  analogWrite(E1_PWM, MOTOR_SPEED);  // Middle
  analogWrite(E4_PWM, MOTOR_SPEED);  // Ring+Pinky

  delay(THUMB_DELAY);
  // Start thumb
  analogWrite(E3_PWM, MOTOR_SPEED);
  delay(THUMB_RETRACT_TIME);
  // Stop thumb at 50%
  analogWrite(E3_PWM, 0);

  // Wait for other fingers to finish
  delay(FINGER_RETRACT_TIME - THUMB_RETRACT_TIME - THUMB_DELAY);

  stopAllMotors();
}

void performPeaceSign() {
  Serial.println(F("Peace Sign..."));

  // Retract middle, ring+pinky, and thumb (keep index+middle extended)
  digitalWrite(M1_DIR, HIGH);   // Middle retract
  digitalWrite(M3_DIR, LOW);    // Thumb retract
  digitalWrite(M4_DIR, HIGH);   // Ring+Pinky retract

  analogWrite(E1_PWM, MOTOR_SPEED);  // Middle
  analogWrite(E4_PWM, MOTOR_SPEED);  // Ring+Pinky

  delay(THUMB_DELAY);
  // Start thumb
  analogWrite(E3_PWM, MOTOR_SPEED);
  delay(THUMB_RETRACT_TIME);
  // Stop thumb at 50%
  analogWrite(E3_PWM, 0);

  // Wait for other fingers to finish
  delay(FINGER_RETRACT_TIME - THUMB_RETRACT_TIME - THUMB_DELAY);

  stopAllMotors();
}

void performThumbOnly() {
  Serial.println(F("Thumb Only..."));

  // Retract thumb only
  digitalWrite(M3_DIR, LOW);    // Thumb retract
  analogWrite(E3_PWM, MOTOR_SPEED);

  delay(THUMB_RETRACT_TIME);
  // Stop thumb at 50%
  analogWrite(E3_PWM, 0);

  stopAllMotors();
}

void performIndexOnly() {
  Serial.println(F("Index Only..."));
  // Retract index only
  digitalWrite(M2_DIR, LOW);    // Index retract
  analogWrite(E2_PWM, MOTOR_SPEED);   // Index Finger

  delay(FINGER_RETRACT_TIME);
  stopAllMotors();
}

void performMiddleOnly() {
  Serial.println(F("Middle Only..."));
  // Retract middle only
  digitalWrite(M1_DIR, HIGH);   // Middle retract
  analogWrite(E1_PWM, MOTOR_SPEED);  // Middle Finger

  delay(FINGER_RETRACT_TIME);
  stopAllMotors();
}

void performRingPinkyOnly() {
  Serial.println(F("Ring+Pinky Only..."));
  // Retract ring+pinky only
  digitalWrite(M4_DIR, HIGH);   // Ring+Pinky retract
  analogWrite(E4_PWM, MOTOR_SPEED); // Ring+Pinky

  delay(FINGER_RETRACT_TIME);
  stopAllMotors();
}

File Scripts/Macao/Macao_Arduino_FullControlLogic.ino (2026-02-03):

//////////////////////////////////////////////////////////////////////////////
// EMG-Triggered Multi-Grasp System for ARARA UNO Prosthetic //
//////////////////////////////////////////////////////////////////////////////
// Combined EMG trigger detection with button & keyboard grasp control
//
// CONTROL FLOW:
// 1. Buttons pre-select a grasp (but don't execute)
// 2. EMG muscle contraction triggers the pre-selected grasp
// 3. Keyboard inputs work as before (immediate execution)
//
// Button Controls:
// Button 1 (Pin 1):  Open Hand (immediate execution)
// Button 2 (Pin 9):  Pre-select Power Grasp
// Button 3 (Pin 13): Pre-select Fine Pinch
// Button 4 (Pin 10): Pre-select Tripod
//
// Keyboard Controls (via Serial) - Immediate execution:
// Key 0: Open Hand (all fingers extended)
// Key 1: Power Grasp (all fingers closed)
// Key 2: Fine Pinch (thumb + middle closed, index + ring+pinky extended)
// Key 3: Tripod (thumb + middle + index closed, ring+pinky extended)
// Key 4: Point (thumb + middle + ring+pinky closed, index extended)
// Key 5: Peace Sign (thumb + ring+pinky closed, index + middle extended)
// Key 6: Close Thumb only
// Key 7: Close Index only
// Key 8: Close Middle only
// Key 9: Close Ring+Pinky only
//
// EMG Sensor: DFRobot Gravity Analog EMG Sensor on pin A5
// - Detects sudden increases in muscle activity
// - Triggers the pre-selected grasp when spike detected
//
// EMG SIGNAL PROCESSING ARCHITECTURE:
// This system uses a three-path processing approach for robust spike detection:
//
// 1. FAST PATH (α=0.25, ~8ms time constant):
//    - Primary signal for spike detection
//    - Tracks muscle contractions with minimal delay (~30ms latency)
//    - Updates continuously (never frozen)
//
// 2. NOISE PATH (Welford's algorithm, ~5s time constant):
//    - Estimates background noise statistics (mean, variance)
//    - Updates only during low-activity periods (velocity-gated)
//    - Used to set adaptive detection thresholds
//
// 3. DC PATH (median filter, ~10s time constant):
//    - Tracks slow baseline drift (temperature, skin contact)
//    - Immune to spikes via median calculation
//    - FROZEN during grasp execution to prevent drift
//
// SPIKE DETECTION:
// - Velocity-based gating: checks rate of signal change
// - CFAR-inspired double threshold (primary + guard)
// - Spike buffer: maintains recent 32 samples for baseline calculation
// - All baselines frozen during graspInProgress flag
//
// BASELINE FREEZE MECHANISM (graspInProgress flag):
// - Critical for preventing drift during motor execution
// - When set to TRUE: DC path and Noise path stop updating
// - Fast path continues (never frozen)
// - Prevents motor noise and hand position changes from corrupting baselines
// - Must be set before ALL motor operations (buttons, keyboard, EMG triggers)
//
// MEMORY USAGE: ~1280 bytes (vs 1440 bytes in old system)
// LATENCY: ~30ms (vs 100ms in old system)
//////////////////////////////////////////////////////////////////////////////
// Written & Maintained by: Rudy de Lange
// Last maintained: 09/01/2026 - Redesigned EMG processing architecture
// Bug fixes applied: 09/01/2026 - Fixed 5 critical bugs
//////////////////////////////////////////////////////////////////////////////

#if defined(ARDUINO) && ARDUINO >= 100
#include "Arduino.h"
#else
#include "WProgram.h"
#endif

#include "EMGFilters.h"

// ========== MOTOR PINS ==========
#define M1_DIR 4     // Index finger
#define E1_PWM 3
#define M2_DIR 7     // Ring + Pinky
#define E2_PWM 6
#define M3_DIR 8     // Thumb
#define E3_PWM 5
#define M4_DIR 12    // Middle finger
#define E4_PWM 11

// ========== BUTTON PINS ==========
#define BUTTON_1 1   // Open Hand (immediate)
#define BUTTON_2 9   // Pre-select Power Grasp
#define BUTTON_3 13  // Pre-select Fine Pinch
#define BUTTON_4 10  // Pre-select Tripod

// ========== EMG SENSOR ==========
#define SensorInputPin A5           // EMG sensor connected to A5

// ========== TIMING CONSTANTS ==========
#define FINGER_EXTEND_TIME 3000
#define FINGER_RETRACT_TIME 3000
#define THUMB_RETRACT_TIME 2300    // 1/2 of full retraction
#define THUMB_DELAY 480            // Delay before thumb starts closing
#define THUMB_PINCH_DELAY 200      // Delay before thumb starts closing for fine pinch
#define DEBOUNCE_DELAY 50          // Button debounce delay in ms

// ========== MOTOR SPEEDS ==========
#define MOTOR_SPEED 255

// ========== EMG CONFIGURATION ==========
#define BAUD_RATE 115200           // IMPROVED: Increased from 9600 to 115200 for faster serial communication
#define UPDATE_INTERVAL 20         // Update serial plotter every 20ms (50 Hz)

// Y-axis scaling for Serial Plotter
#define Y_AXIS_MIN 0
#define Y_AXIS_MAX 70000  // MODIFIED: Increased from 45000 to 70000 for better spike visibility

// EMG Filter setup
EMGFilters myFilter;
int sampleRate = SAMPLE_FREQ_500HZ;  // 500 Hz sampling
int humFreq = NOTCH_FREQ_50HZ;       // 50 Hz notch filter (change to NOTCH_FREQ_60HZ if in US)

// Timing for plotter updates
unsigned long lastPlotTime = 0;

// ========== SIGNAL PROCESSING CONSTANTS ==========
// Fast Path: Primary signal tracking (α=0.25, ~8ms time constant)
#define FAST_EMA_ALPHA 0.25f        // Fast response for spike detection

// Noise Path: Background noise estimation (~5s time constant)
#define NOISE_UPDATE_INTERVAL 250   // Update noise stats every 250 samples (~0.5s)
#define VELOCITY_GATE_THRESHOLD 50.0f // Only update noise when velocity < threshold

// DC Path: Slow baseline drift tracking (~10s time constant)
#define DC_BUFFER_SIZE 16           // Median filter size (keep small for Arduino)
#define DC_UPDATE_INTERVAL 500      // Update DC baseline every 500 samples (~1s)

// Spike Buffer: Recent samples for baseline calculation
#define SPIKE_BUFFER_SIZE 32        // Must be power of 2 for efficient wrapping

// Detection Thresholds
#define PRIMARY_THRESHOLD_K 3.5f    // Primary threshold (K × noise_std)
#define GUARD_THRESHOLD_K 2.5f      // Guard threshold for confirmation
#define MIN_PRIMARY_THRESHOLD 800.0f // Minimum absolute threshold
#define MIN_GUARD_THRESHOLD 500.0f  // Minimum guard threshold

// Timing
#define TRIGGER_COOLDOWN 3000       // 3 second cooldown after grasp execution (ms)
#define CALIBRATION_SAMPLES 5000    // Collect 5000 samples (~10 seconds at 500Hz)

// ========== GLOBAL VARIABLES ==========
// Fast Path
float fastSignal = 0.0f;            // Fast EMA output
float prevFastSignal = 0.0f;        // Previous sample for velocity calculation

// Noise Path (Welford's algorithm for online variance)
float noiseMean = 0.0f;             // Running mean of noise
float noiseM2 = 0.0f;               // Running sum of squared differences
unsigned long noiseSampleCount = 0; // Number of samples in noise estimate
unsigned int noiseSamplesSinceUpdate = 0; // Counter for update interval
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

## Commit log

2026-02-03 Added folder structure
    [Severus_BOM_Control_and_Price_Tracking.xlsx]
2026-02-03 Added all files for the Macao
    [Finger Base.stl, Finger Distal Pad.stl, Finger Distal Phalange.stl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]
2026-02-03 Added .STL/.STEP files for all hands
    [Ararauna Finger Assembly.step, Back Cover.stl, Distal Phalange.stl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]
2026-02-03 Added Scripts + Missing .STL/.STEP for Severus
    [Ararauna_Arduino.ino, Macao_Arduino_EducationControlProgram.ino, Macao_Arduino_FullControlLogic.ino]
